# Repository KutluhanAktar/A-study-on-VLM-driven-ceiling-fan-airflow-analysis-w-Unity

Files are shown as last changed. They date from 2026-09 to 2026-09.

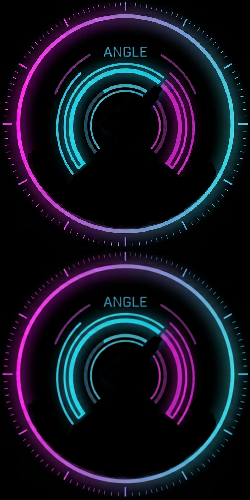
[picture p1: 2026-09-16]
Mobile Application/assets/angle_indicator_bg.png

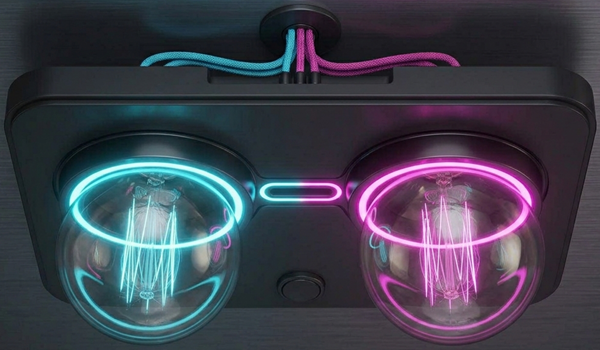
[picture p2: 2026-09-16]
Mobile Application/assets/dual_light_full_open.png

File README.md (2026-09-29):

> I developed my portfolio website — kutluhanaktar.com — from scratch and decided to migrate all of my codebase to GitHub to provide a simple and straightforward experimentation or replication method for my proof-of-concept projects. Nonetheless, since I focused on demonstrating my thought process and experiment results thoroughly in the written tutorial format, including but not limited to PCB and 3D model designing steps, I could not provide enough information to fully explain my concepts and instructions via GitHub descriptions only. Thus, I highly recommend inspecting the associated project tutorials and videos on my portfolio website or other platforms (maker communities), i.e., Hackster, Hackaday, and Instructables.

# Original Project Publication Date

**September 29, 2026**

# Description

**Utilizing VLMs to determine dual fan configurations for optimum cooling based on LiDAR-oriented real-time airflow simulations on Unity.**

As consecutive heatwaves were passing through my region at the beginning of Summer, I had been intrigued to develop a research project regarding AI-oriented HVAC simulations to increase real-world cooling efficiency both energy-wise and coverage-wise. Although there were meticulous research papers, even commercial firms providing services to analyze the cooling efficiency of air conditioning units by thorough HVAC simulations, I decided to focus on developing my project around ceiling fans. Even though ceiling fans are not as popular as air conditioning units nowadays, I had noticed there were a plethora of ceiling fan installations in my city, especially in historic shopping districts, bazaars, and government establishments. Thus, I decided to focus my research on simulating ceiling fan-induced airflow and deriving optimal system settings from this simulation for efficient cooling.

Considering I wanted to see the impact of AI-oriented simulations on deriving optimum configurations for a real-world ceiling fan system, I decided to design a dual ceiling fan mechanism from scratch, enabling me to control all experiment parameters while building my ceiling fan airflow simulation program. Though a little untraditional, I decided to base my dual ceiling fan design on a differential bevel gear mechanism to be able to move both fans 180° vertically and 360° horizontally, leading to a lot more complicated but comprehensive simulation-driven airflow analysis and real-world cooling efficiency improvements.

After deciding on the bare bones of the dual ceiling fan mechanism, I needed a method to map the surroundings of operating ceiling fans since a precise airflow simulation must include real-time obstacle updates to analyze airflow path fluctuations triggered by solid surfaces such as walls, open doors, windows, or even moving people. Generally, HVAC simulations for industrial settings utilize highly sensitive 3D LiDARs with SLAM or sensor fusion techniques to generate accurate heat maps. Nonetheless, since I wanted to focus on fan-produced indoor airflow analysis for much simpler settings, I decided to utilize an RPLIDAR A1M8-R6 LiDAR scanner and turn its 2D scan points into a simple 3D obstacle map in my airflow simulation program, enabling fan-produced air displacement routes (trails) to bounce off of their surfaces.

In the spirit of making the ceiling airflow simulation program easily accessible and open-source, I decided to utilize Unity to develop all airflow analysis features, including the obstacle generation from 2D LiDAR scan points, without utilizing any third-party or paid Unity services. Although Unity might seem like an odd choice since it is a cross-platform, performance-focused 3D game engine, I wanted to capitalize on its advanced scene and animation rendering features in order to simulate accurate airflow fluctuations and track fan-produced air displacement routes (trails). In this regard, I was able to obtain animation-based frames individually for each pre-defined ceiling fan configuration (angles, fan strength, etc.), enabling me to conduct airflow analysis by taking instances from a long animation (video) sequence.

To derive optimal ceiling fan configurations from selected airflow simulation frames so as to achieve real-world efficient cooling, I decided to utilize vision–language models (VLMs) running locally. As I wanted to demonstrate the performance of open-source vision–language models without tailoring model output for a specific ceiling fan-installed space, I did not train any models beforehand. In this regard, I was able to see whether off-the-shelf open-weight vision–language models could be deployed to obtain airflow simulation-based ceiling fan configurations to achieve energy-efficient and optimal cooling of a real-world closed environment. I thoroughly discussed my findings in the following tutorial, but I can briefly state that the vision-language models (Qwen) I employed performed well and provided effective fan configurations based on the obstacle map derived from 2D LiDAR scan points.

- Qwen2.5-VL-7B-Instruct
- Qwen3-VL-8B-Instruct

As I wanted to calculate 2D LiDAR scan points, execute the Unity ceiling fan-produced airflow simulation application, and run vision-language models on the same device to achieve fast and reliable simulation-based airflow analysis results, I decided to utilize the Qualcomm Dragonwing IQ-9075 Evaluation Kit (EVK), which is a compact development platform optimized for industrial IoT, Edge AI, and robotics applications involving heavy workloads. Thanks to the IQ-9075's dedicated AI Engine (Hexagon NPU) for on-device AI, I was able to execute operations separately to achieve excellent calculation, simulation, and inference performance, which is still bemusing to me considering the compactness of the EVK :)

To provide a user-friendly interface to select Unity-generated airflow simulation frames and communicate with the provided vision-language models, I developed a simple web application running on Flask, behaving as the intermediary between the Unity airflow simulation application and the local LLM/VLM server — Qualcomm Docker Compose container.

- Octa-core Kryo CPU ➡️ LiDAR scan points and other calculations
- Adreno GPU (with CPU) ➡️ Unity airflow simulation application
- Hexagon NPU ➡️ Vision-language models (VLMs)

Even though I obtained great airflow analysis results from vision-language models, I did not want to create a direct pipeline between the VLM outputs and ceiling fan mechanism controls, considering potential hallucinations and false positives. Furthermore, I wanted to enable the user to access all of the ceiling fan mechanism controls without impediments by not concealing fan configurations behind VLM outputs, including the dual light bulbs I added, since the ceiling fan with an on-device light source is a widely preferred household good. Since I did not want to create a secondary web-based interface for the fan configurations, I decided to develop a BLE-enabled mobile (Android) application, embedding the previously mentioned intermediary (Flask) web application. In this regard, all of the ceiling fan mechanism controls and VLM interactions can be inspected and adjusted on a single mobile application. The mobile application allows the user to:

- ✅ adjust ceiling fan vertical (180°) and horizontal (360°) angles for both fans,
- ✅ adjust ceiling fan strength magnitudes from 1 to 4,
- ✅ control light source states (on or off),
- ✅ observe current vertical angles and horizontal axis alignment states,
- ✅ connect to the intermediary web application to interact with the provided VLMs.

To enable the mobile application to manage ceiling fan mechanism configurations over BLE without putting any additional stress on the compute power of the IQ-9075 EVK, I decided to utilize a separate board, Arduino Nano 33 BLE, to control all mechanical features. I designed a unique 4-layer PCB to build a compact fan control unit based on the Nano 33 BLE, which provides all the required connections for the external power source, stepper motor drivers, DC motor drivers, lights, rotary encoders, optical speed modules, etc., to execute all of the ceiling fan mechanism features noted above.

As a proof-of-concept research project, I did not focus on building a directly installable ceiling fan system ready to cool an enclosed space like a commercially available product. Instead, I focused on developing a VLM-assisted ceiling fan mechanism that showcases intricate circuit connections, wiring, device structure, and a simulation-based airflow analysis pipeline. Thus, I immensely scaled down the intertwined VLM-assisted ceiling fan mechanism I envisioned and highlighted the fan elevation by placing the whole mechanism on an IKEA LACK table, which enabled me to create a highly detailed digital twin of the ceiling fan system in Fusion 360 and integrate this exquisite 3D model into the Unity Editor to develop an utterly accurate Unity airflow simulation application, estimating airflow fluctuations and air displacement routes (trails) based on the fan elevation and the LiDAR-detected obstacles.

# Inspect the project tutorial on:

- **[kutluhanaktar.com](https://www.kutluhanaktar.com/projects/A_study_on_VLM_driven_ceiling_fan_airflow_analysis_w_Unity/)**
- **[Hackster](https://www.hackster.io/kutluhan-aktar/a-study-on-vlm-driven-ceiling-fan-airflow-analysis-w-unity-9c8947)**
- **[Instructables](https://www.instructables.com/A-Study-on-VLM-driven-Ceiling-Fan-Airflow-Analysis/)**
- **[Arduino Project Hub](https://projecthub.arduino.cc/kutluhan_aktar)**
- **[Hackaday](https://hackaday.io/project/206717-a-study-on-vlm-driven-ceiling-fan-airflow-analysis)**

model_design_0<br>

model_design_3<br>

model_design_12_fan_mechanism<br>

model_design_35_fan_mechanism<br>

model_design_36_fan_mechanism<br>

assembly_68_fan_mechanism_diff<br>

unity_project_set_up_11_scale_color_mat<br>

unity_project_set_up_50_rplidar_a1_link_init_test<br>

unity_project_set_up_53_lidar_trail_tests<br>

iq9_software_setup_42_run_unity_app_box64<br>

iq9_software_setup_43_run_unity_app_box64<br>

assembly_142_legs<br>

device_run_1_test<br>

device_run_4_test<br>

android_app_run_10<br>

android_app_run_11<br>

android_app_run_12<br>

iq9_run_all_3_first_exp<br>

android_app_run_13<br>

android_app_run_15<br>

android_app_run_16<br>

android_app_run_18<br>

android_app_run_20<br>

android_app_run_21<br>

android_app_run_23<br>

android_app_run_24<br>

android_app_run_25<br>

android_app_run_27<br>

android_app_run_29_cont<br>

device_run_11_fan_movement<br>

android_app_run_35_cont<br>

device_run_16_fan_movement<br>

android_app_run_39_cont<br>

device_run_19_fan_movement<br>

android_app_run_46_cont<br>

device_run_23_fan_movement<br>

android_app_run_51_cont<br>

device_run_29_lights<br>

android_app_run_54_cont<br>

device_run_37_angle_zeroing<br>

android_app_run_56_cont<br>

device_run_40_scnerio_2_door_open<br>

iq9_run_all_9_second_exp<br>

android_app_run_58_scenerio_2<br>

device_run_41_scnerio_2_door_closed<br>

iq9_run_all_12_second_exp_door_closed<br>

android_app_run_61_scenerio_2_8b<br>

android_app_run_64_scenerio_2_8b<br>

android_app_run_66_scenerio_2_8b<br>

iq9_run_all_13_second_exp_recorded<br>

device_run_42_scnerio_3_cam_move<br>

iq9_run_all_18_third_exp_camera_pos_change<br>

android_app_run_72_scenerio_3_cam_move

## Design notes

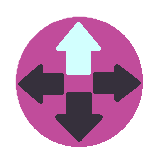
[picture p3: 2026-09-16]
Mobile Application/assets/fan_joystick_knob_c_up.png

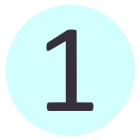
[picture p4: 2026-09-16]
Mobile Application/assets/fan_slider_knob_1.png

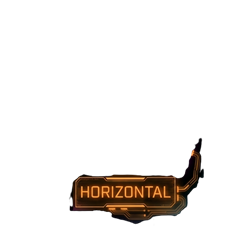
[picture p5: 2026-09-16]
Mobile Application/assets/angle_indicator_homed.png

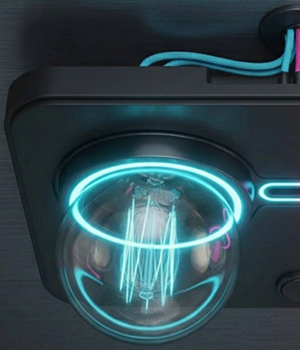
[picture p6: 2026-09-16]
Mobile Application/assets/dual_light_left_open.png

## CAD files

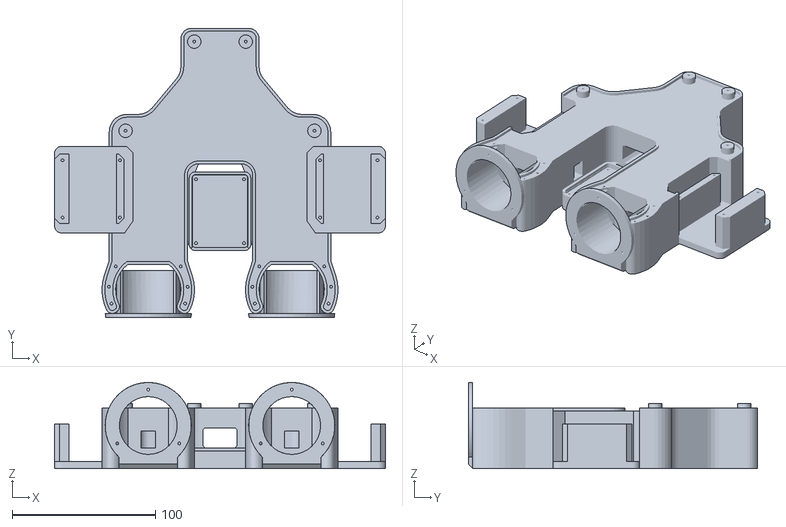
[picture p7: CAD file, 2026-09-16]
Mechanical Components/STL/central_fan_control_unit/ceiling_fan_mechanism v98_ceiling_fan_mechanism v98_central_fan_control_unit_1_main.stl
230.7 x 201.7 x 60.0

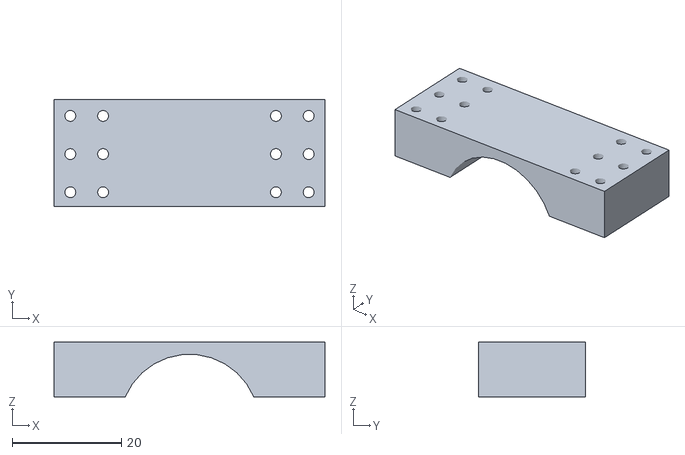
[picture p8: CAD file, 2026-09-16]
Mechanical Components/STL/fan_driver_mechanism/ceiling_fan_mechanism v98_ceiling_fan_mechanism v98_fan_driver_mechanism_1_joint_carrier_gear_cap.stl
49.7 x 19.6 x 10.00

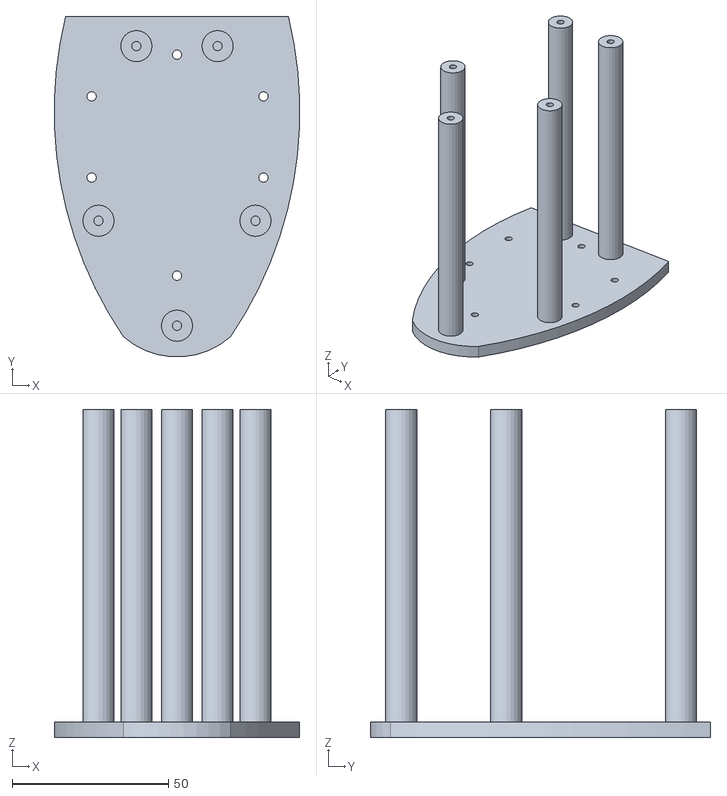
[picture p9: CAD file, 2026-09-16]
Mechanical Components/STL/lidar_stand/ceiling_fan_mechanism v98_ceiling_fan_mechanism v98_lidar_stand_1_stand.stl
78.5 x 108.9 x 105.0

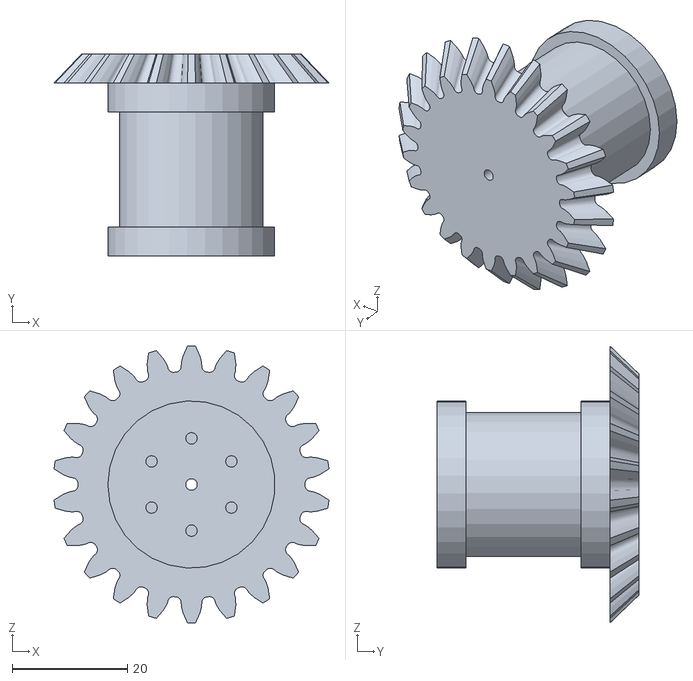
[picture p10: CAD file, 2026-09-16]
Mechanical Components/STL/fan_driver_mechanism/ceiling_fan_mechanism v98_ceiling_fan_mechanism v98_fan_driver_mechanism_1_driver_carrier_bevel_gear.stl
47.7 x 35.0 x 48.0

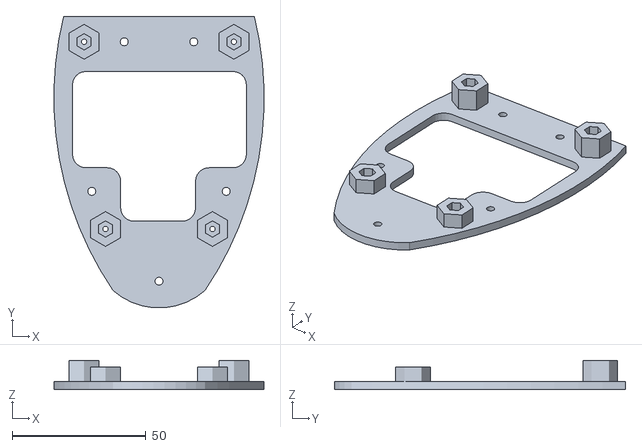
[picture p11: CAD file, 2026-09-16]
Mechanical Components/STL/lidar_stand/ceiling_fan_mechanism v98_ceiling_fan_mechanism v98_lidar_stand_1_mount.stl
78.5 x 108.9 x 11.0

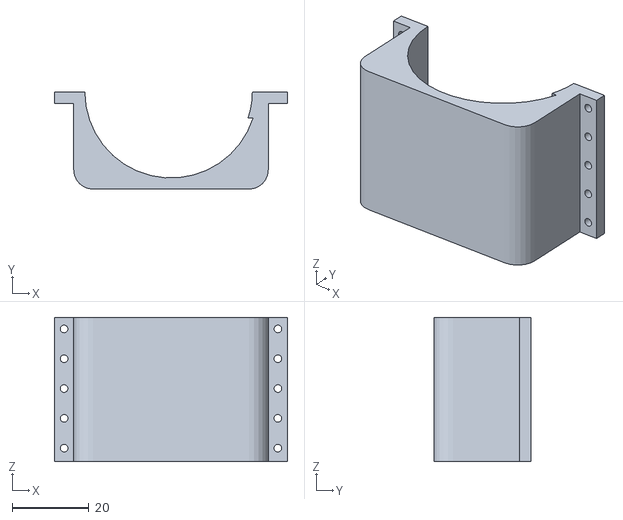
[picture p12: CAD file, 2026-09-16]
Mechanical Components/STL/fan_driver_mechanism/ceiling_fan_mechanism v98_ceiling_fan_mechanism v98_fan_driver_mechanism_1_fan_motor_holder_top.stl
60.6 x 25.3 x 37.5

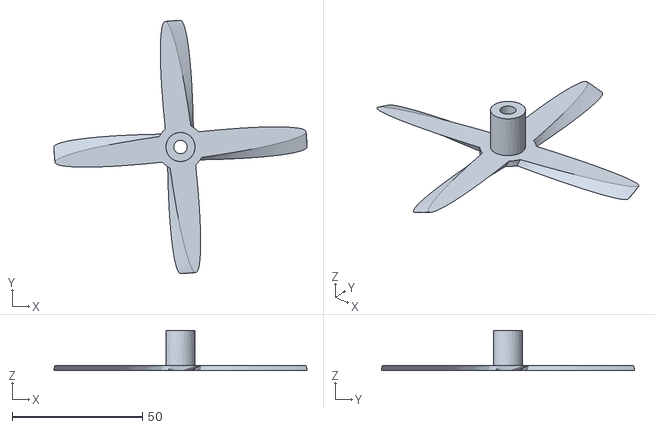
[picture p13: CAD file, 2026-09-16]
Mechanical Components/STL/fan_driver_mechanism/ceiling_fan_mechanism v98_ceiling_fan_mechanism v98_fan_driver_mechanism_1_fan_blades.stl
97.0 x 97.0 x 15.5

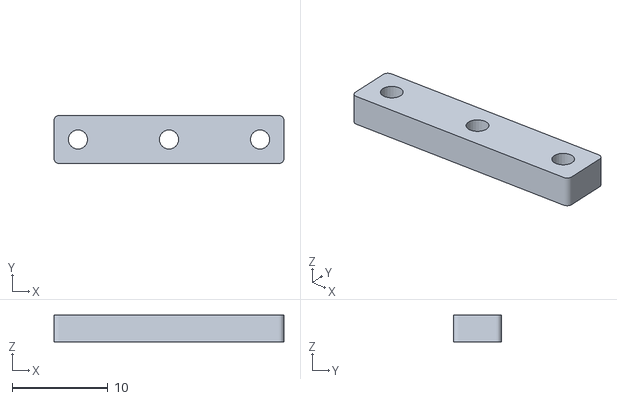
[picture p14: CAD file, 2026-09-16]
Mechanical Components/STL/fan_driver_mechanism/ceiling_fan_mechanism v98_ceiling_fan_mechanism v98_fan_driver_mechanism_1_joint_carrier_support_4.stl
24.0 x 5.00 x 2.80

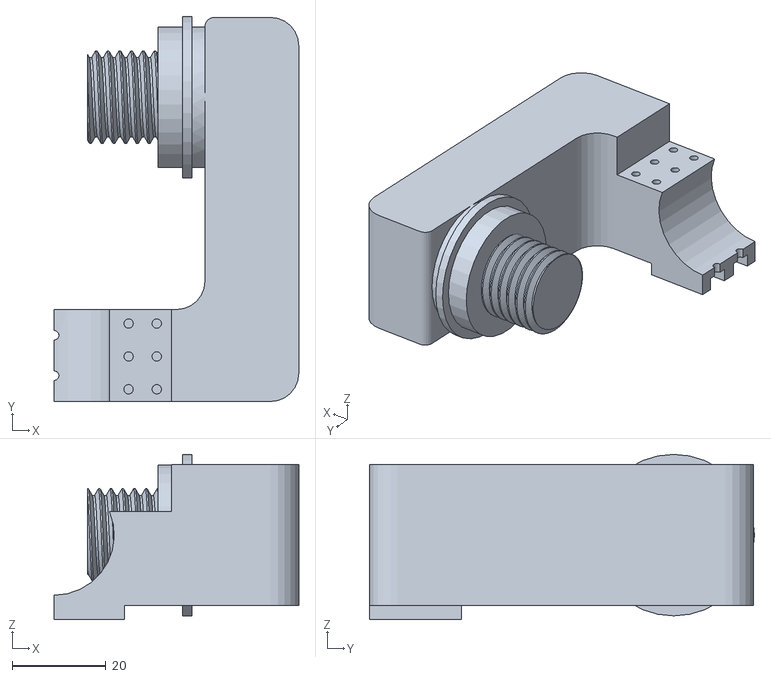
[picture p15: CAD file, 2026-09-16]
Mechanical Components/STL/fan_driver_mechanism/ceiling_fan_mechanism v98_ceiling_fan_mechanism v98_fan_driver_mechanism_1_joint_carrier_l.stl
52.1 x 82.0 x 35.2

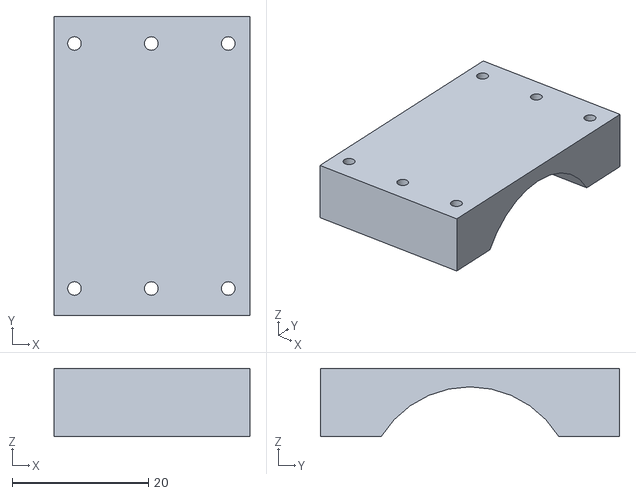
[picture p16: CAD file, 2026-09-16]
Mechanical Components/STL/fan_driver_mechanism/ceiling_fan_mechanism v98_ceiling_fan_mechanism v98_fan_driver_mechanism_1_joint_carrier_pivot_cap.stl
28.8 x 44.0 x 10.0

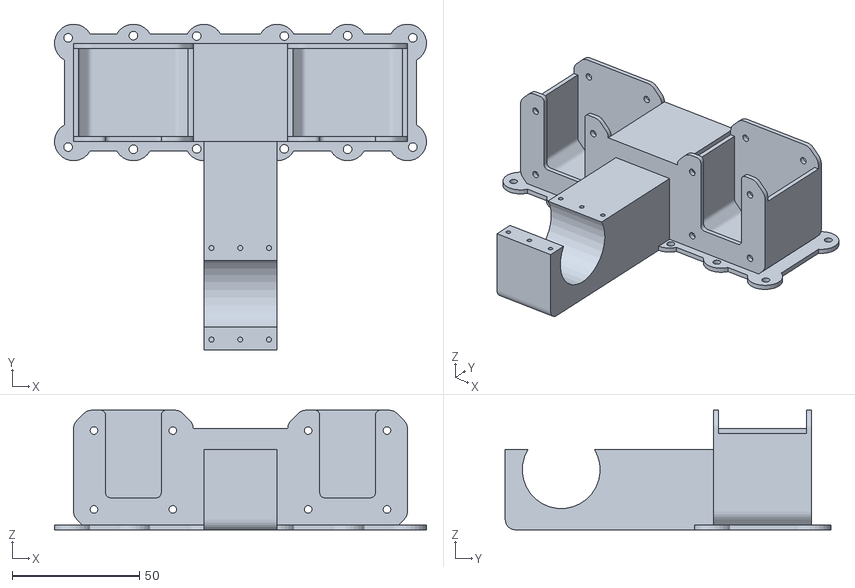
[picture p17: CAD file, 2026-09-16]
Mechanical Components/STL/fan_driver_mechanism/ceiling_fan_mechanism v98_ceiling_fan_mechanism v98_fan_driver_mechanism_1_primary_carrier.stl
146.3 x 128.0 x 47.1

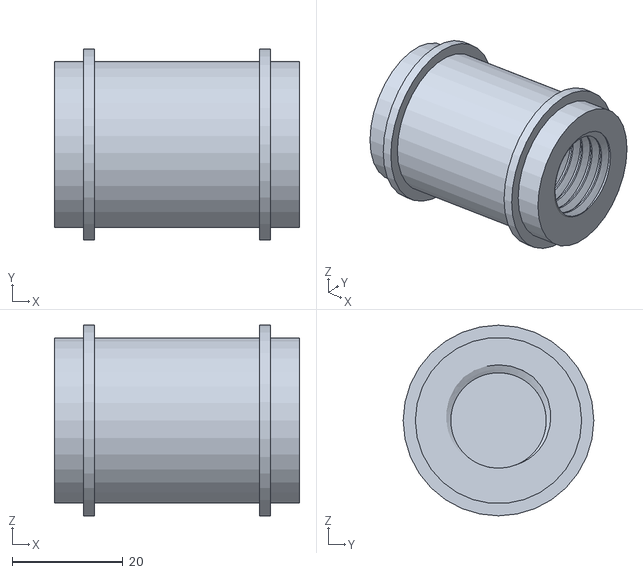
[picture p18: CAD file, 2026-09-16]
Mechanical Components/STL/fan_driver_mechanism/ceiling_fan_mechanism v98_ceiling_fan_mechanism v98_fan_driver_mechanism_1_joint_carrier_pivot.stl
44.2 x 34.4 x 34.4

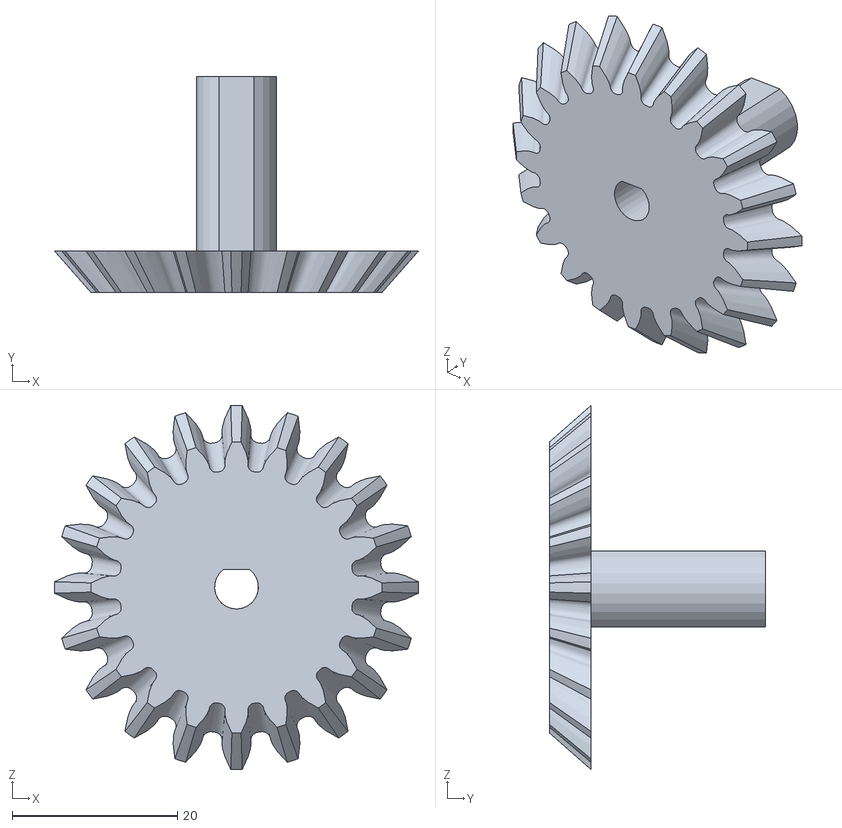
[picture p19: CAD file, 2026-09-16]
Mechanical Components/STL/fan_driver_mechanism/ceiling_fan_mechanism v98_ceiling_fan_mechanism v98_fan_driver_mechanism_1_driver_bevel_gear.stl
44.0 x 26.1 x 44.0

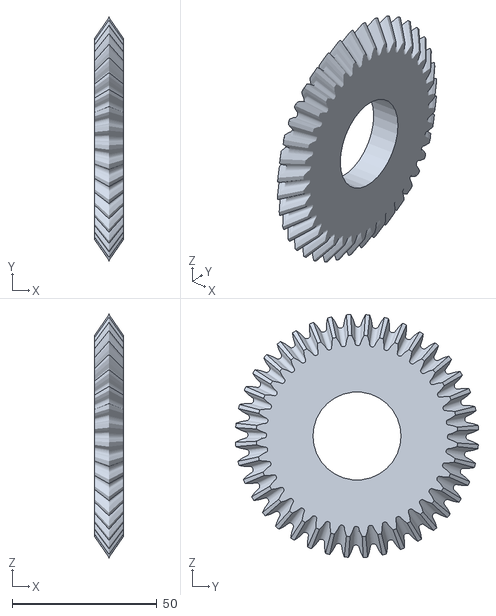
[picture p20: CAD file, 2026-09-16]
Mechanical Components/STL/fan_driver_mechanism/ceiling_fan_mechanism v98_ceiling_fan_mechanism v98_fan_driver_mechanism_1_angle_bevel_gear.stl
10.0 x 83.9 x 83.9

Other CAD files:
Mechanical Components/STL/fan_driver_mechanism/ceiling_fan_mechanism v98_ceiling_fan_mechanism v98_fan_driver_mechanism_1_joint_angle_calibration_stand.stl
Mechanical Components/STL/fan_driver_mechanism/ceiling_fan_mechanism v98_ceiling_fan_mechanism v98_fan_driver_mechanism_1_joint_carrier_support_3.stl
Mechanical Components/STL/fan_driver_mechanism/ceiling_fan_mechanism v98_ceiling_fan_mechanism v98_fan_driver_mechanism_1_joint_carrier_r.stl
Mechanical Components/STL/fan_driver_mechanism/ceiling_fan_mechanism v98_ceiling_fan_mechanism v98_fan_driver_mechanism_1_fan_motor_holder_bottom.stl
Mechanical Components/STL/fan_driver_mechanism/ceiling_fan_mechanism v98_ceiling_fan_mechanism v98_fan_driver_mechanism_1_joint_angle_calibration_pins.stl

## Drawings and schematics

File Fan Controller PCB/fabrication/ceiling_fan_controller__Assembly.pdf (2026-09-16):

1 | 2 | 3 | 4 | 5 | 6

A

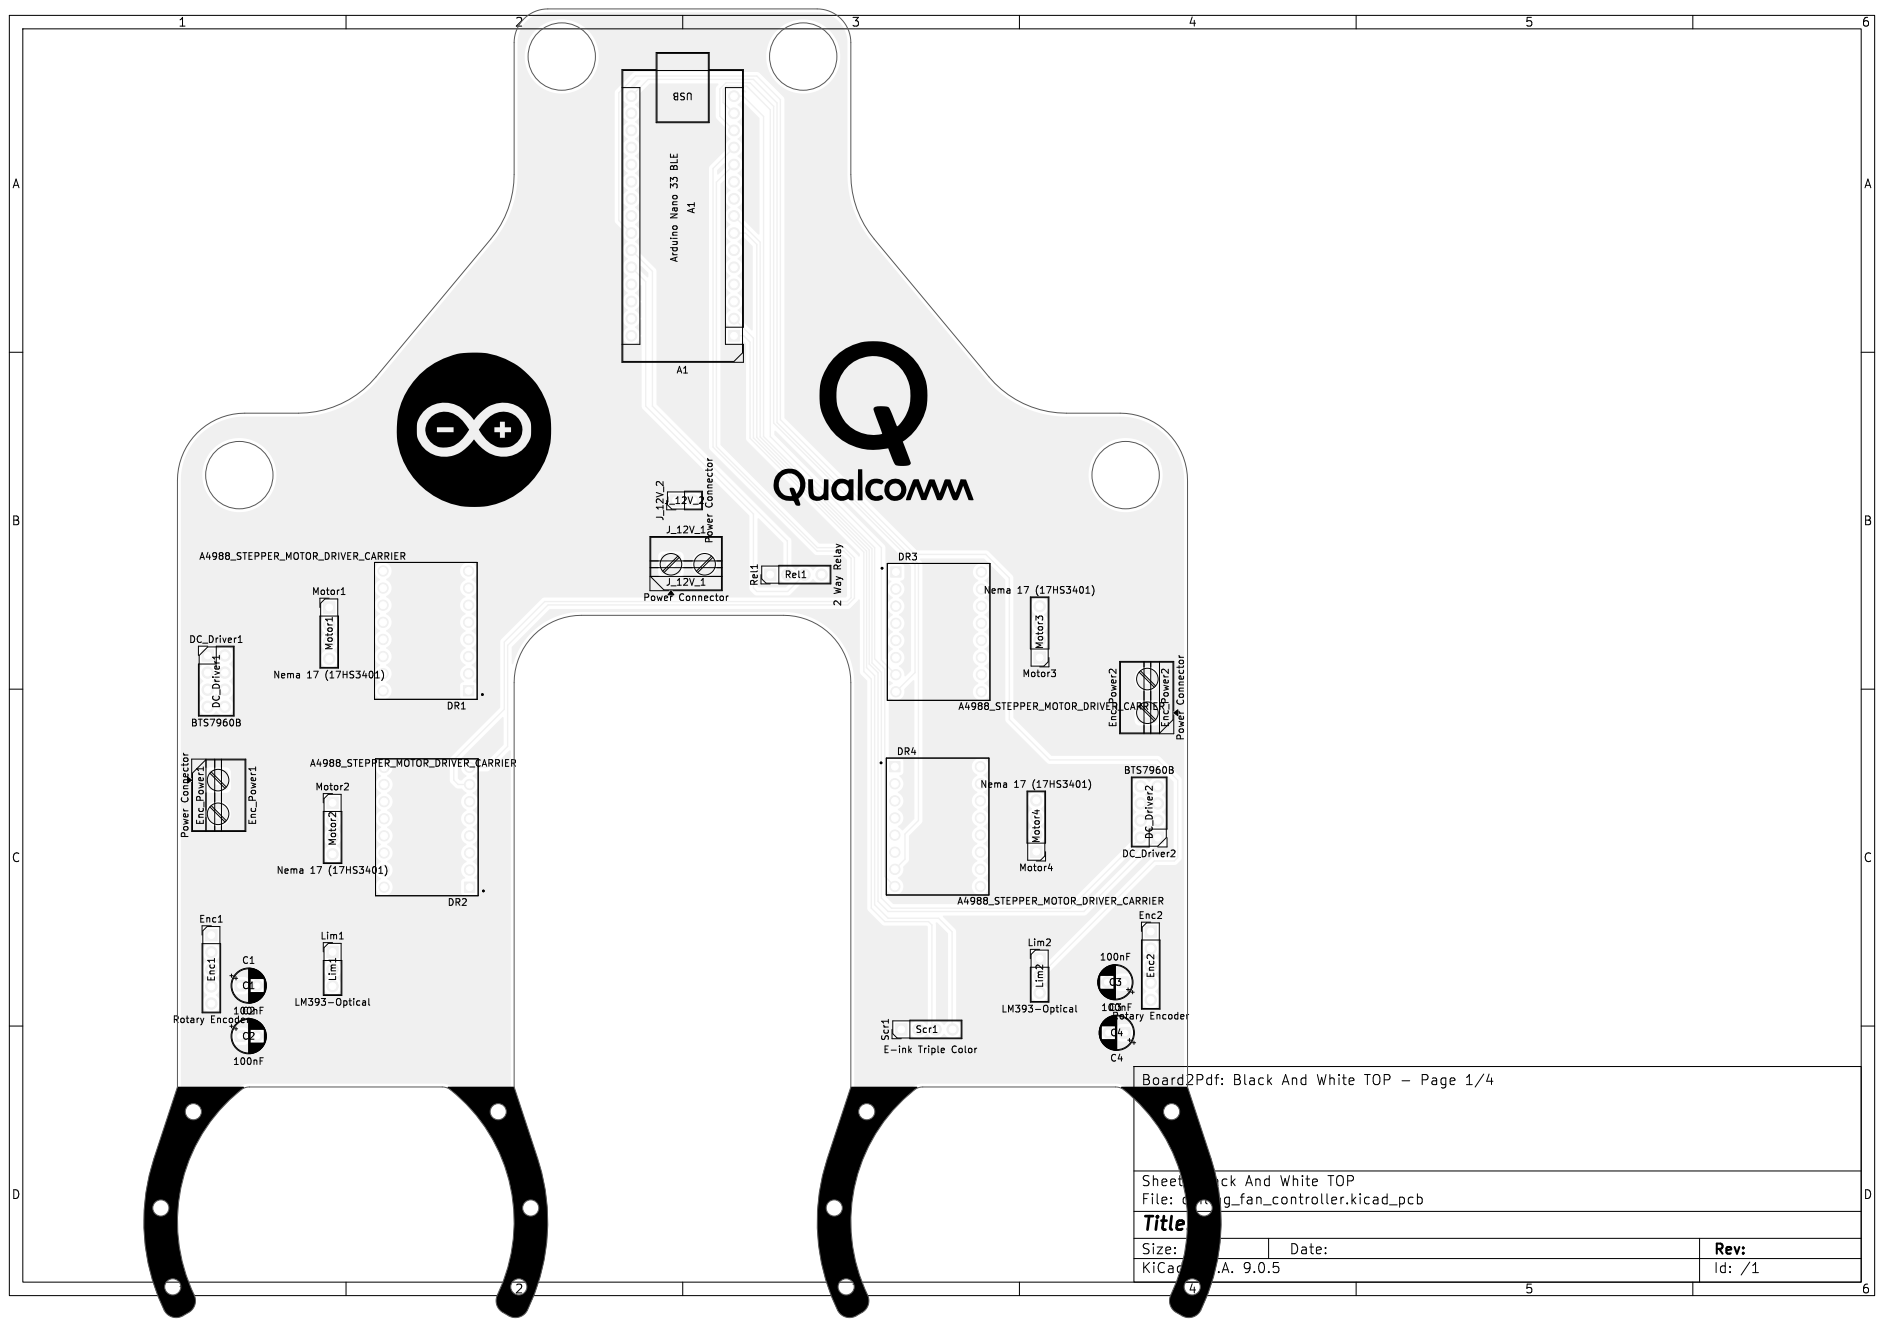
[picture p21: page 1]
Scr1 DC_Driver2 C1 Motor2 Enc_Power1 Rel1 C4 DR1 J_12V_2 J_12V_1 Motor1 DR2 C3; Lim1; Enc2 Enc_Power2 DR4; Motor3 Motor4 DC_Driver1; A1 USB; Lim2 DR3 C2 Enc1; D Date: KiCad; E.D.A. 9.0.5 Size: A4; Rev:; Id: /1 Title: File: ceiling_fan_controller.kicad_pcb Sheet: Black; And; White; TOP; Board2Pdf:; Black; TOP -; Page; E-ink; Triple Color Scr1; BTS7960B DC_Driver2; Nema 17 (17HS3401) Motor2 Power Connector; Enc_Power1; 2 Way Relay Rel1; A4988_STEPPER_MOTOR_DRIVER_CARRIER; Power J_12V_2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

A

A

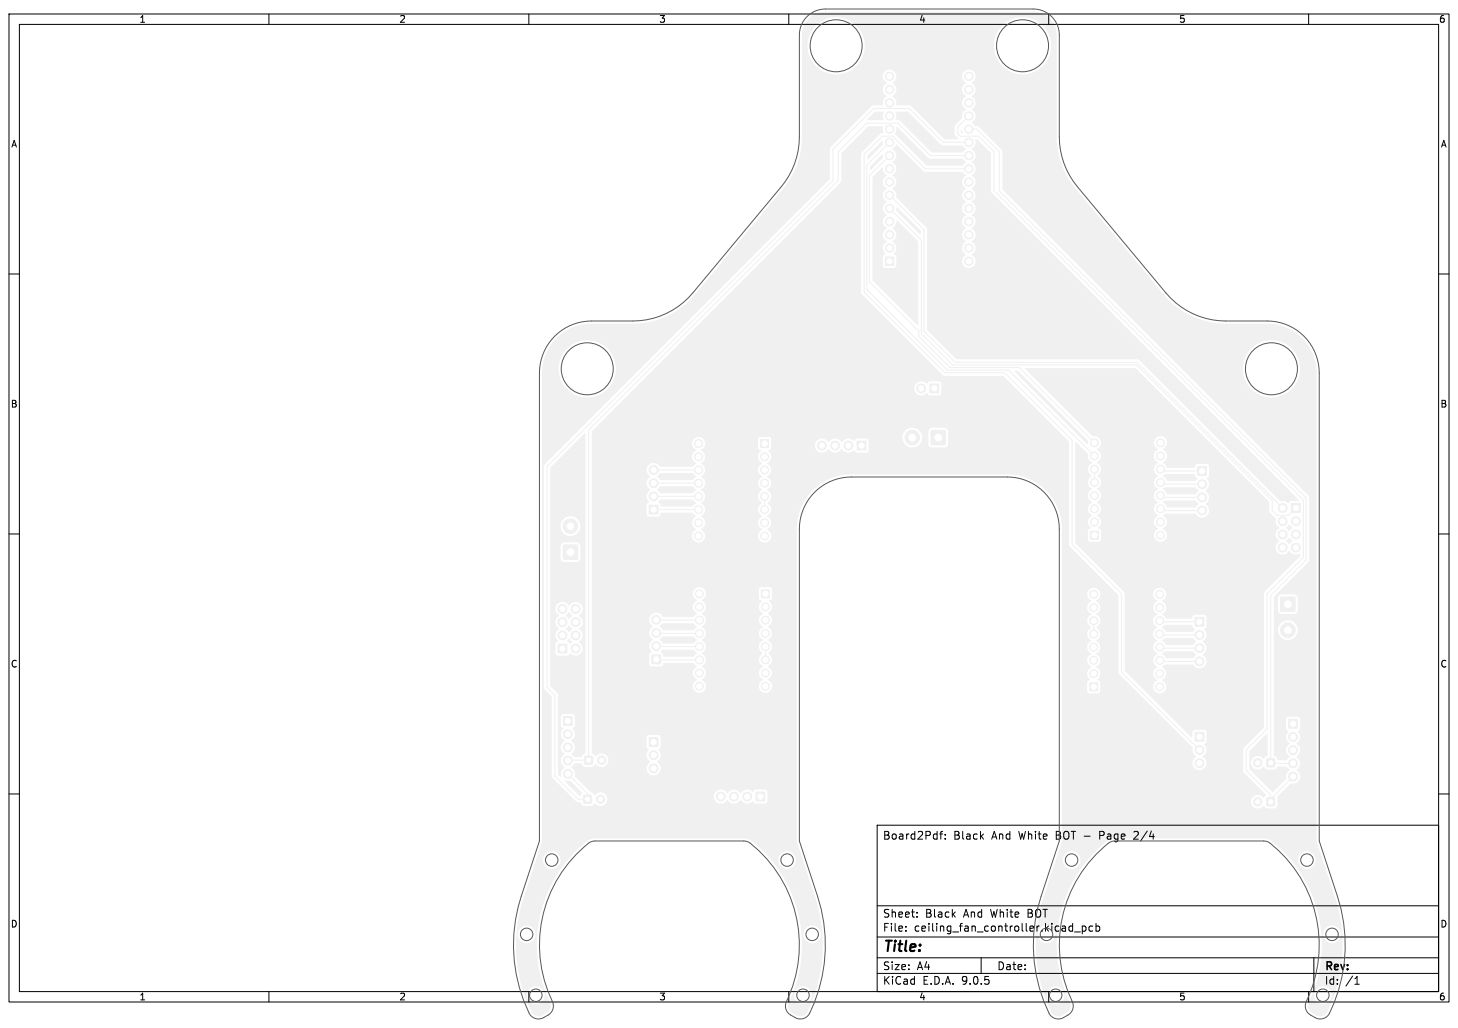
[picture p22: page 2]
D Date: KiCad; E.D.A. 9.0.5 Size: A4; Rev:; Id: /1 Title: File: ceiling_fan_controller.kicad_pcb Sheet: Black; And; White; BOT Board2Pdf:; Black; BOT -; Page 2/4

A

A

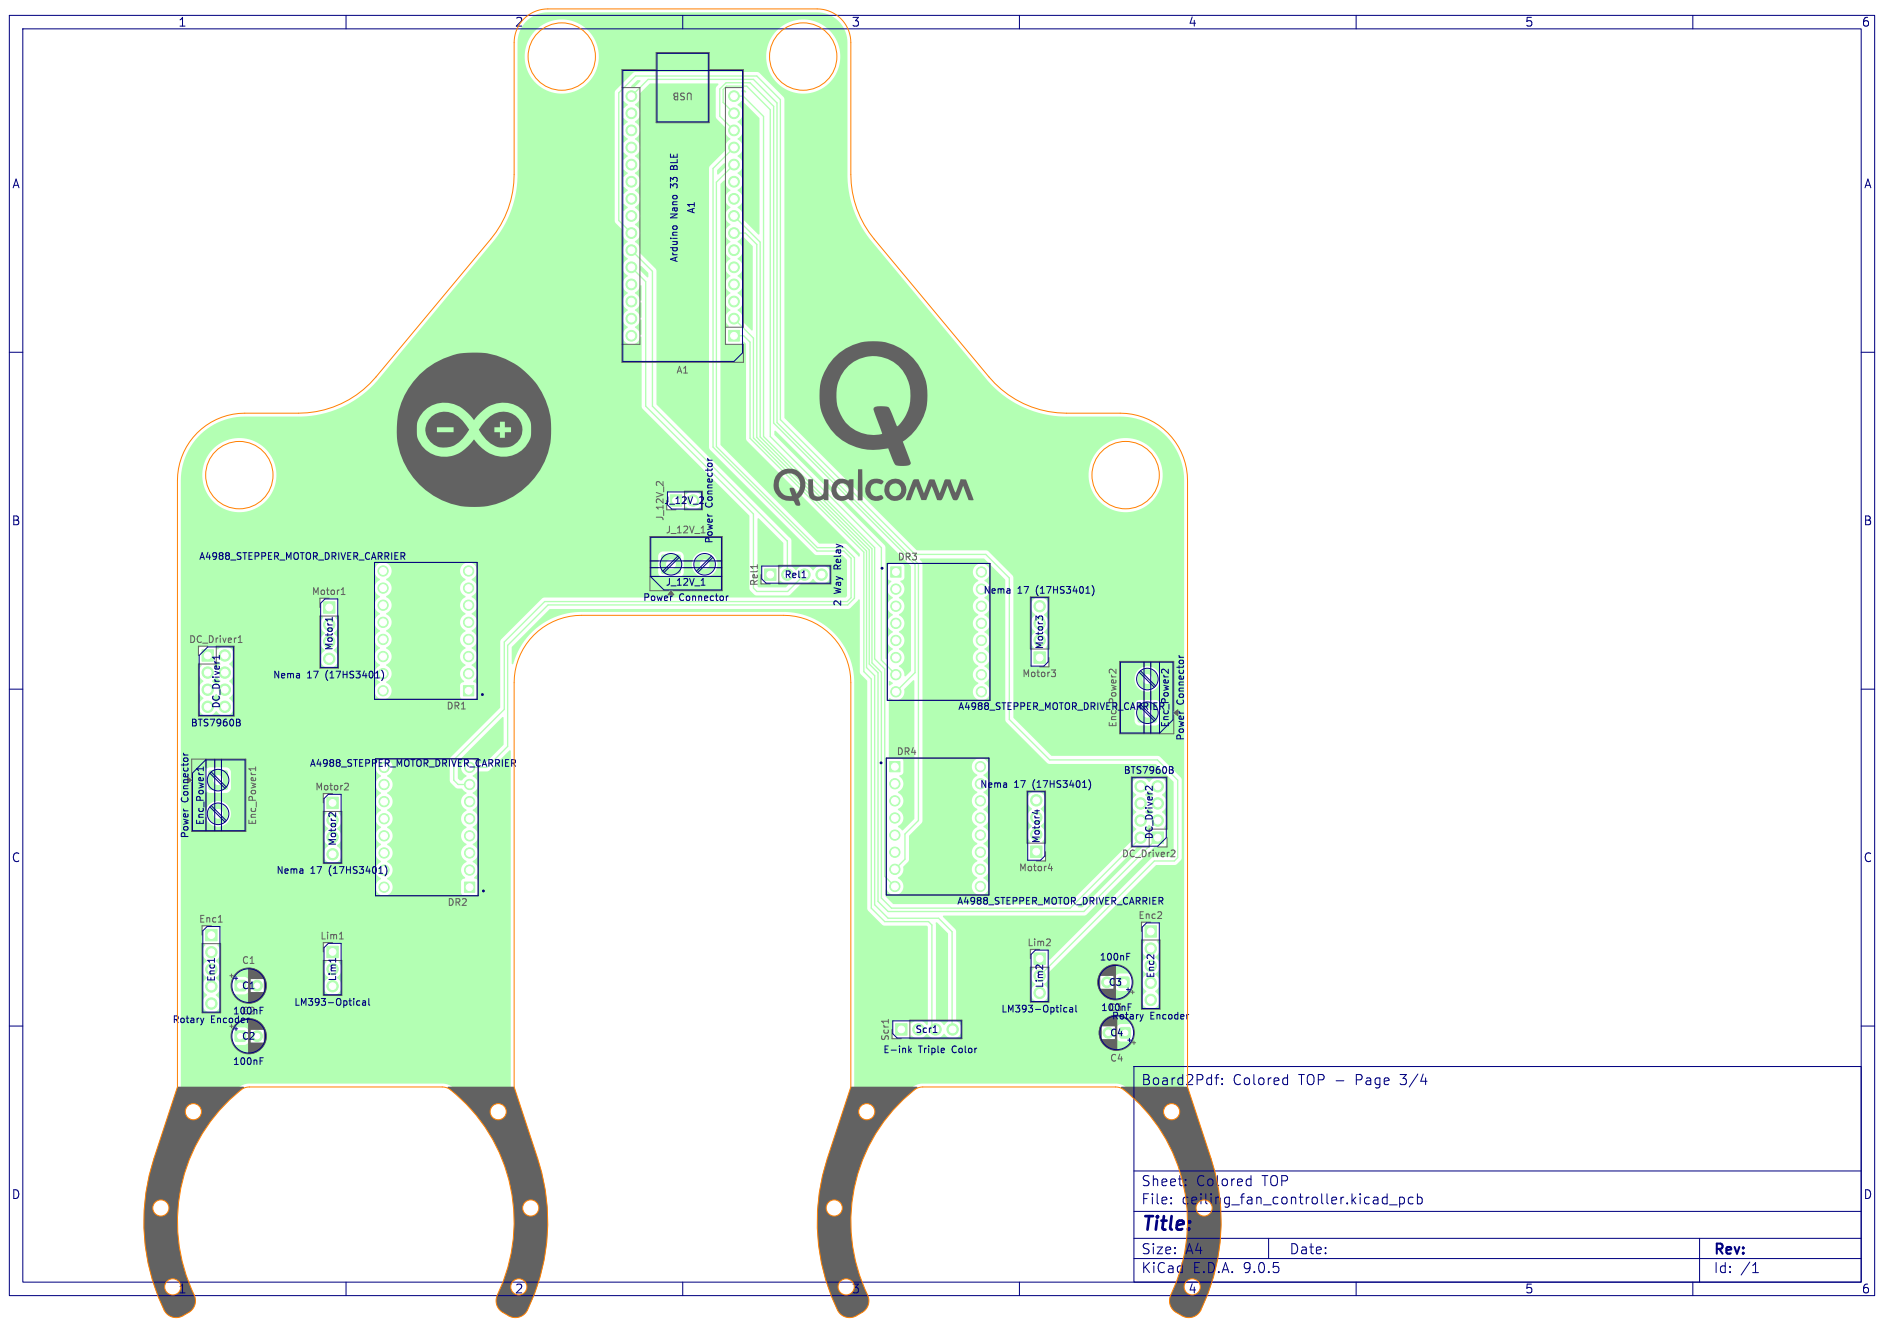
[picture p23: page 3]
Scr1 DC_Driver2 C1 Motor2 Enc_Power1 Rel1 C4 DR1 J_12V_2 J_12V_1 Motor1 DR2 C3; Lim1; Enc2 Enc_Power2 DR4; Motor3 Motor4 DC_Driver1; A1 USB; Lim2 DR3 C2 Enc1; D Date: KiCad; E.D.A. 9.0.5 Size: A4; Rev:; Id: /1 Title: File: ceiling_fan_controller.kicad_pcb Sheet: Colored; TOP; Board2Pdf:; Colored; TOP -; Page 3/4; E-ink; Triple Color Scr1; BTS7960B DC_Driver2; Nema 17 (17HS3401) Motor2 Power Connector; Enc_Power1; 2 Way Relay Rel1; A4988_STEPPER_MOTOR_DRIVER_CARRIER; Power J_12V_2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

A

A

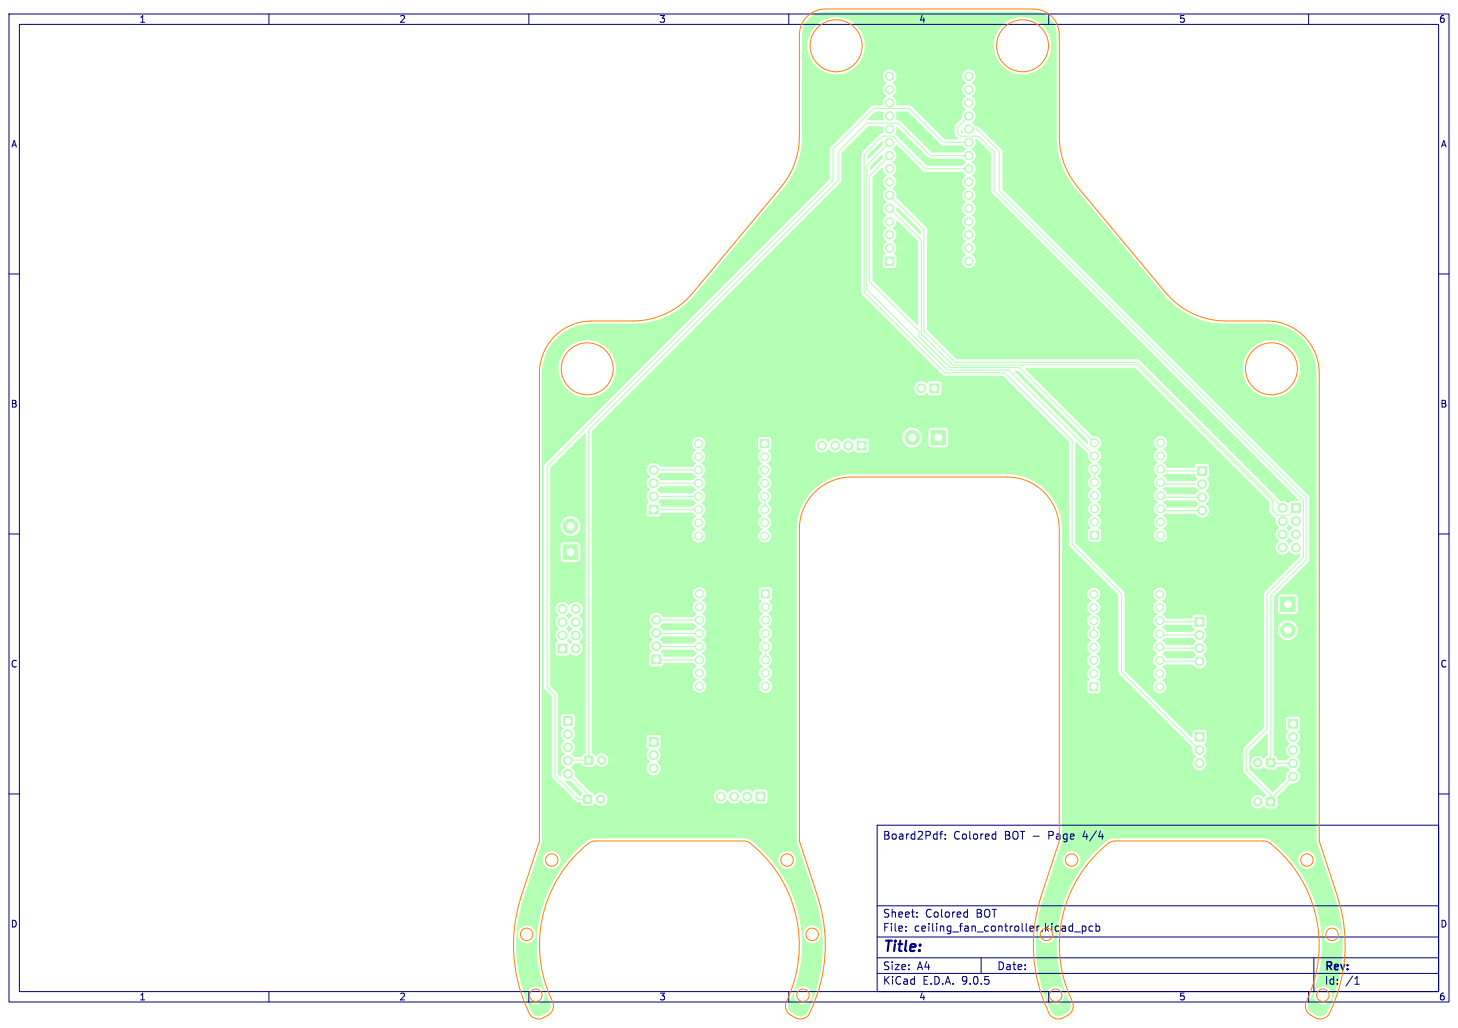
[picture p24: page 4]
D Date: KiCad; E.D.A. 9.0.5 Size: A4; Rev:; Id: /1 Title: File: ceiling_fan_controller.kicad_pcb Sheet: Colored; BOT Board2Pdf:; Colored; BOT -; Page 4/4

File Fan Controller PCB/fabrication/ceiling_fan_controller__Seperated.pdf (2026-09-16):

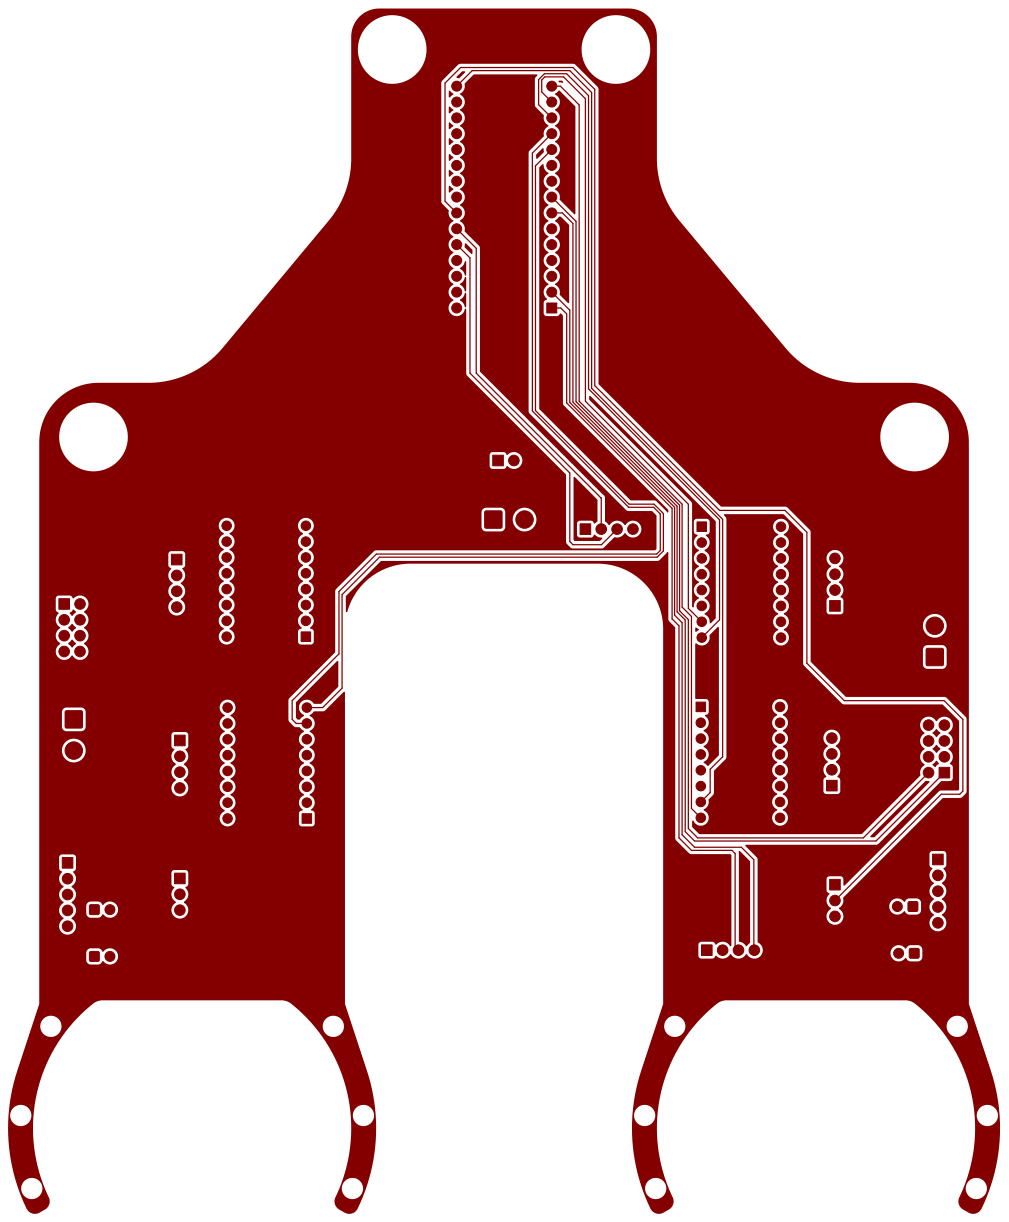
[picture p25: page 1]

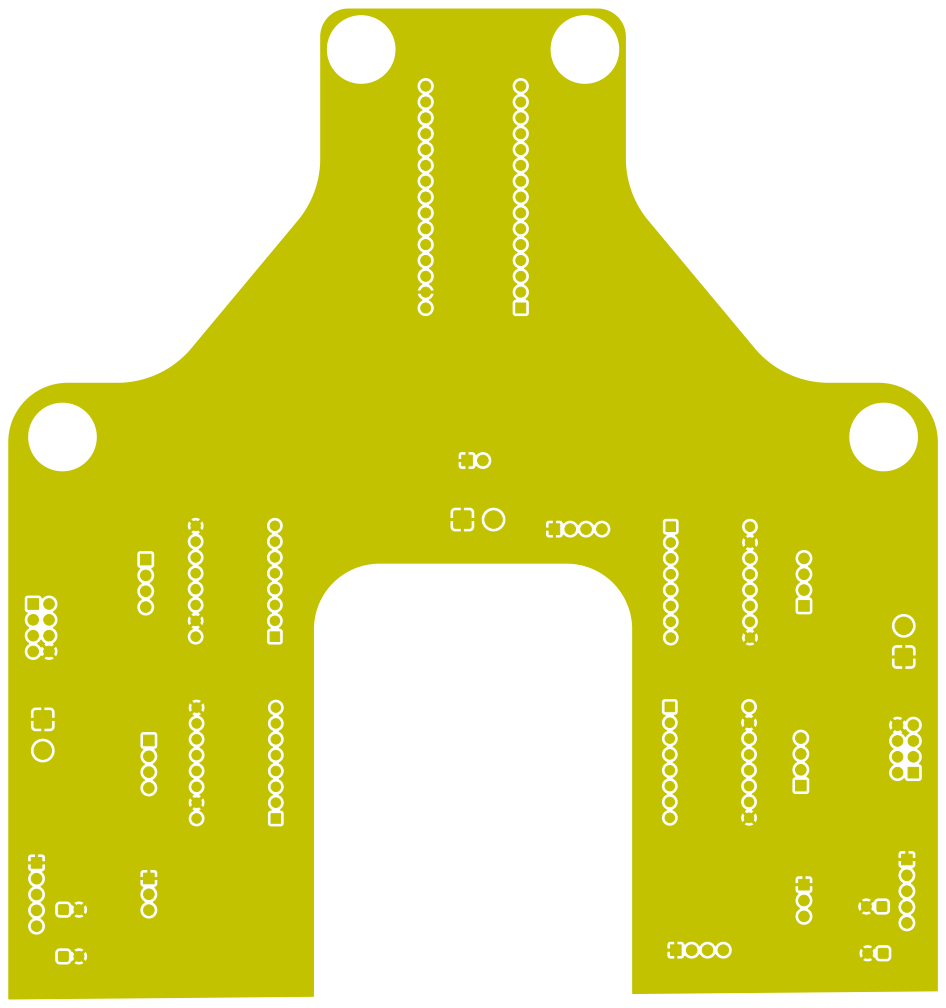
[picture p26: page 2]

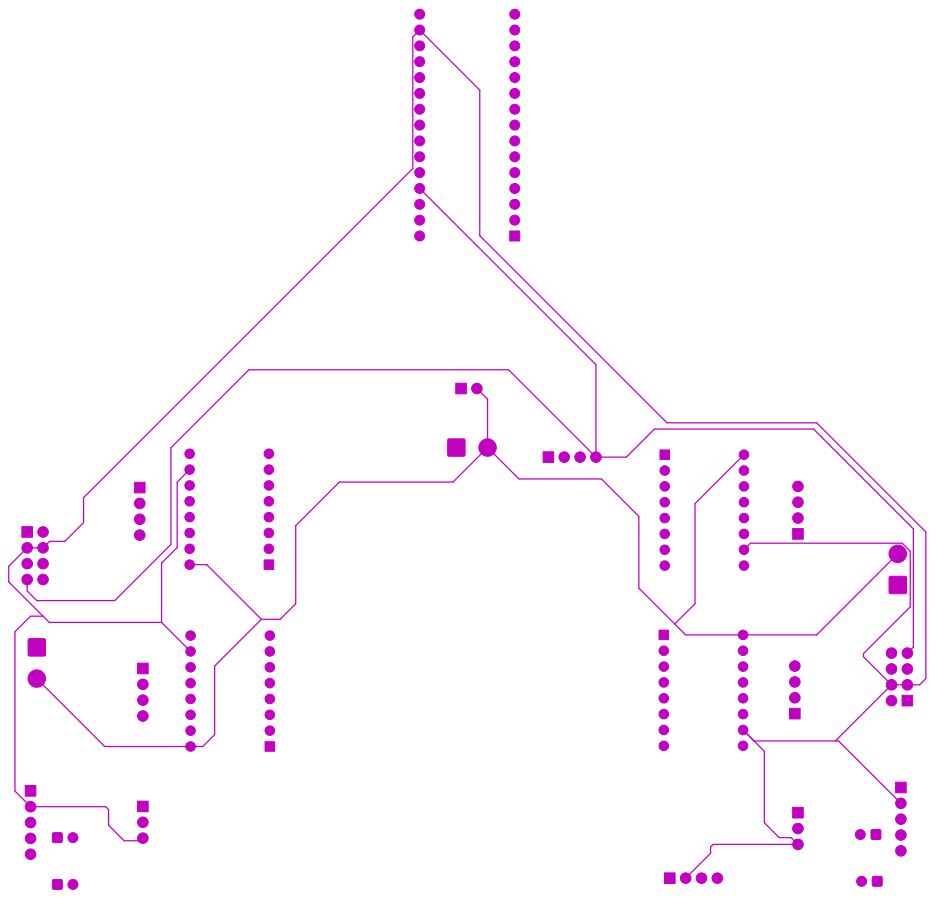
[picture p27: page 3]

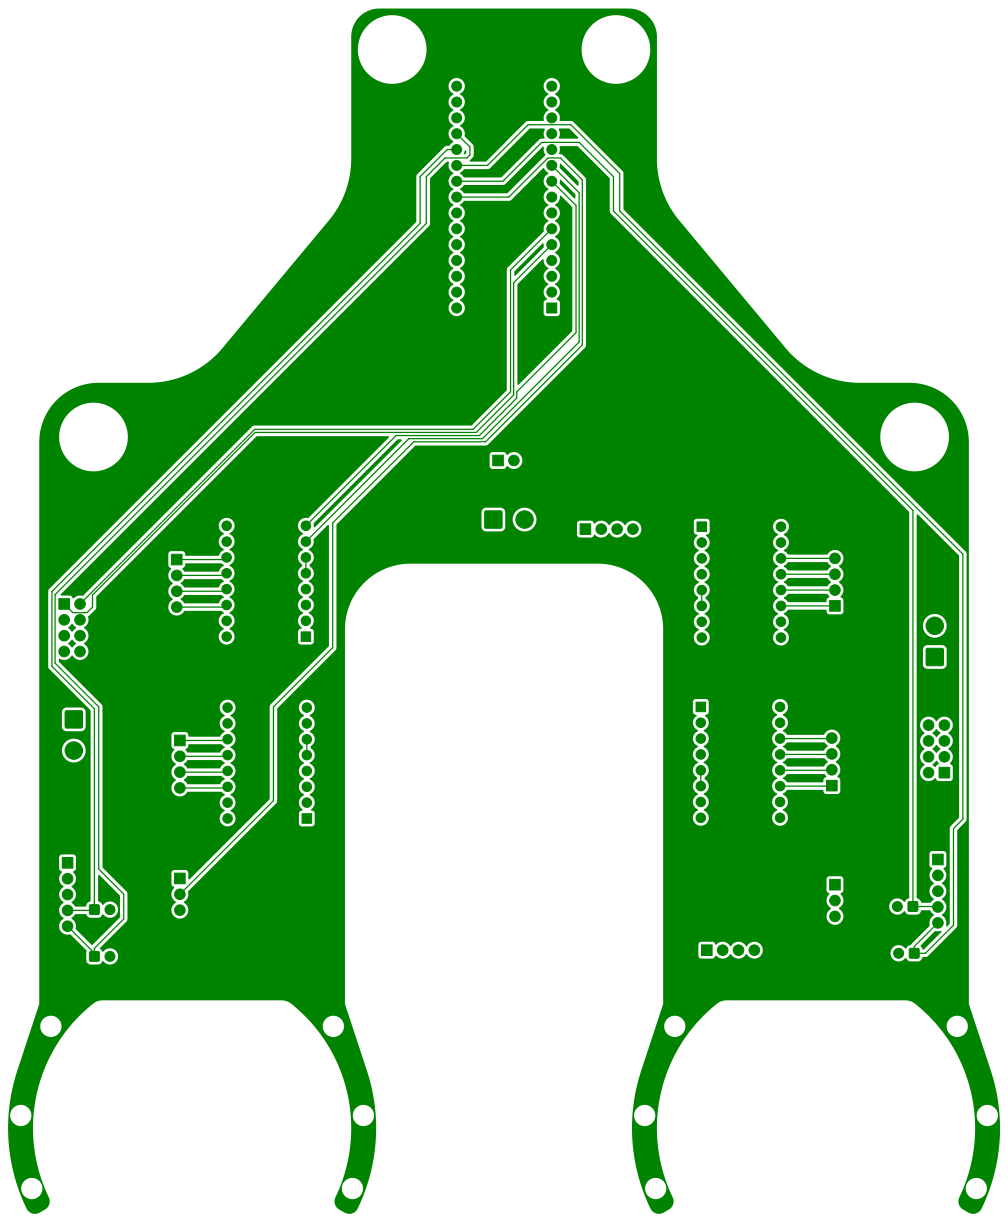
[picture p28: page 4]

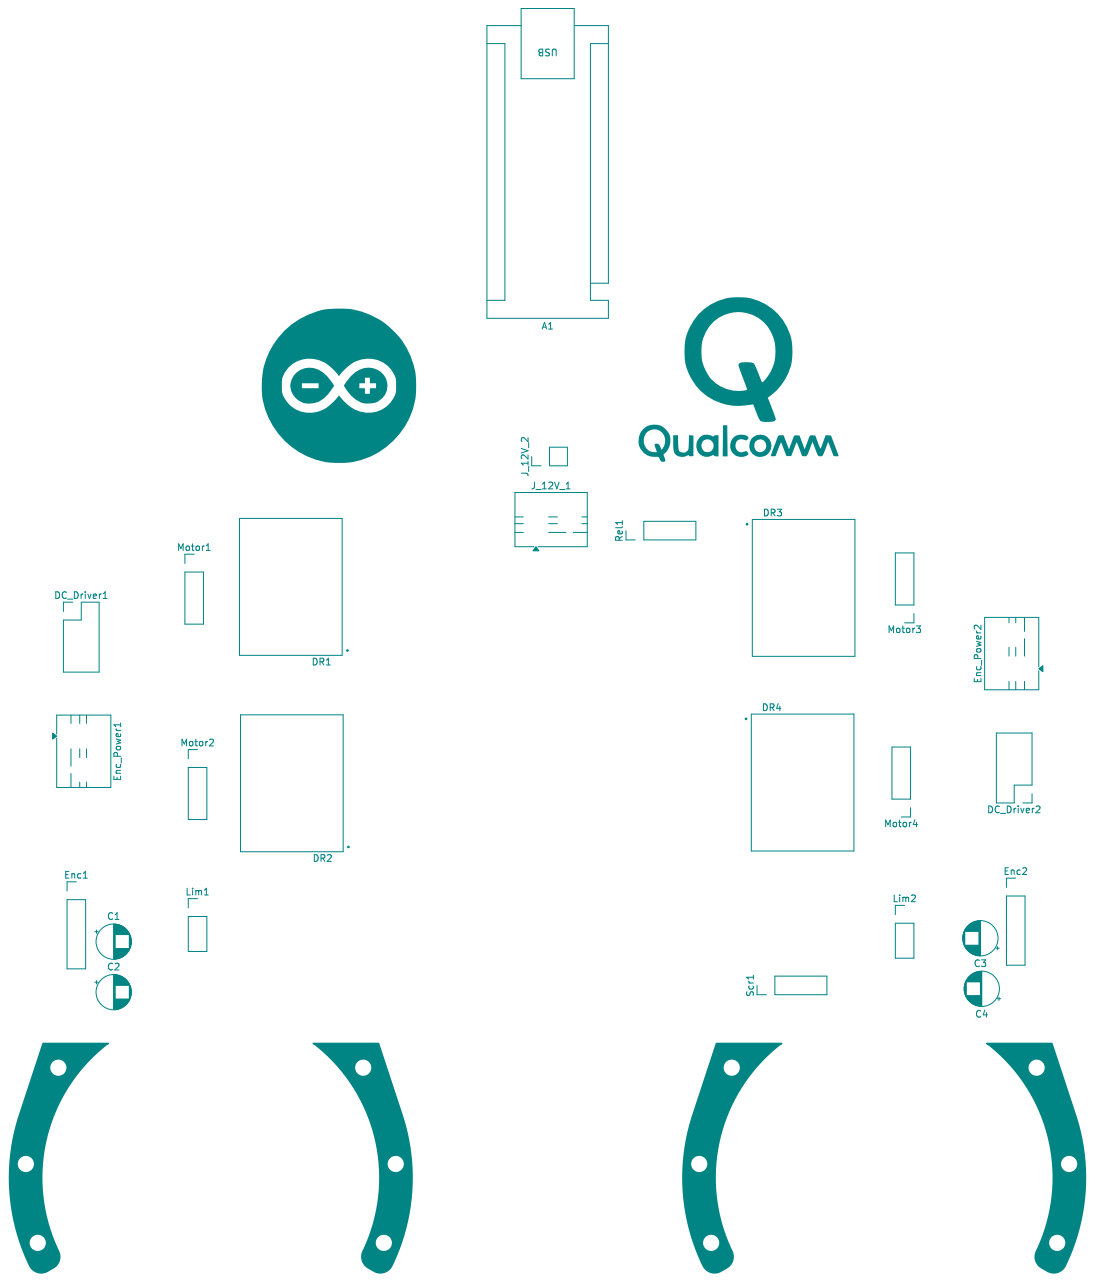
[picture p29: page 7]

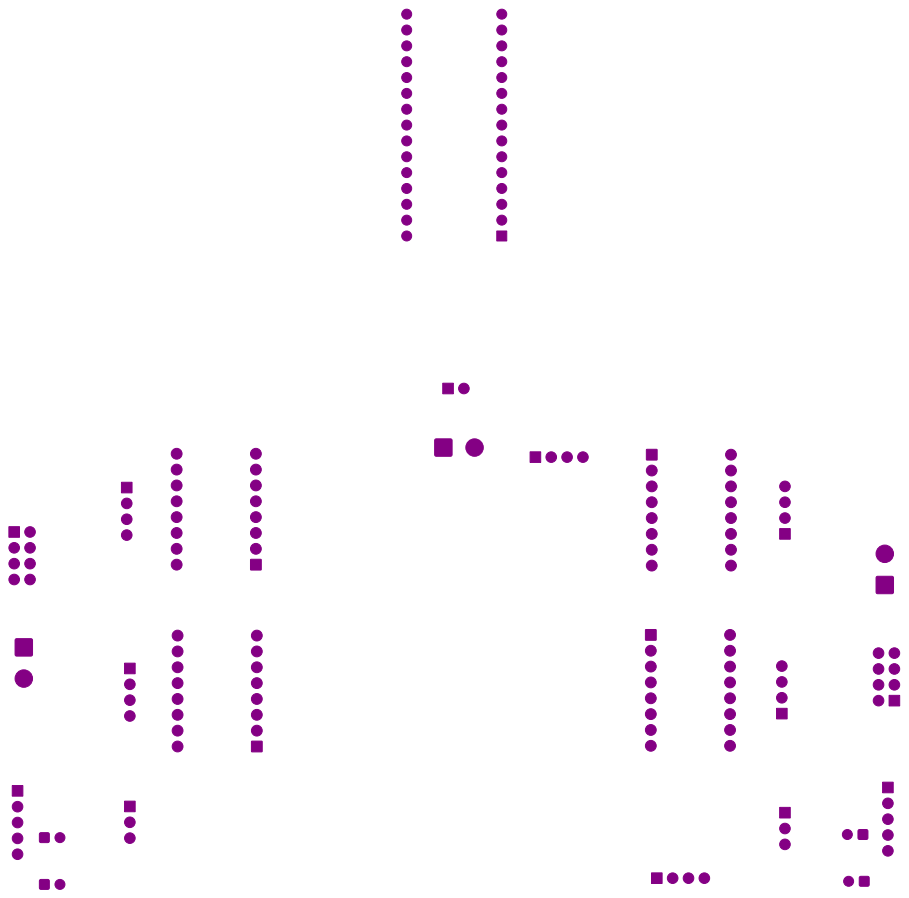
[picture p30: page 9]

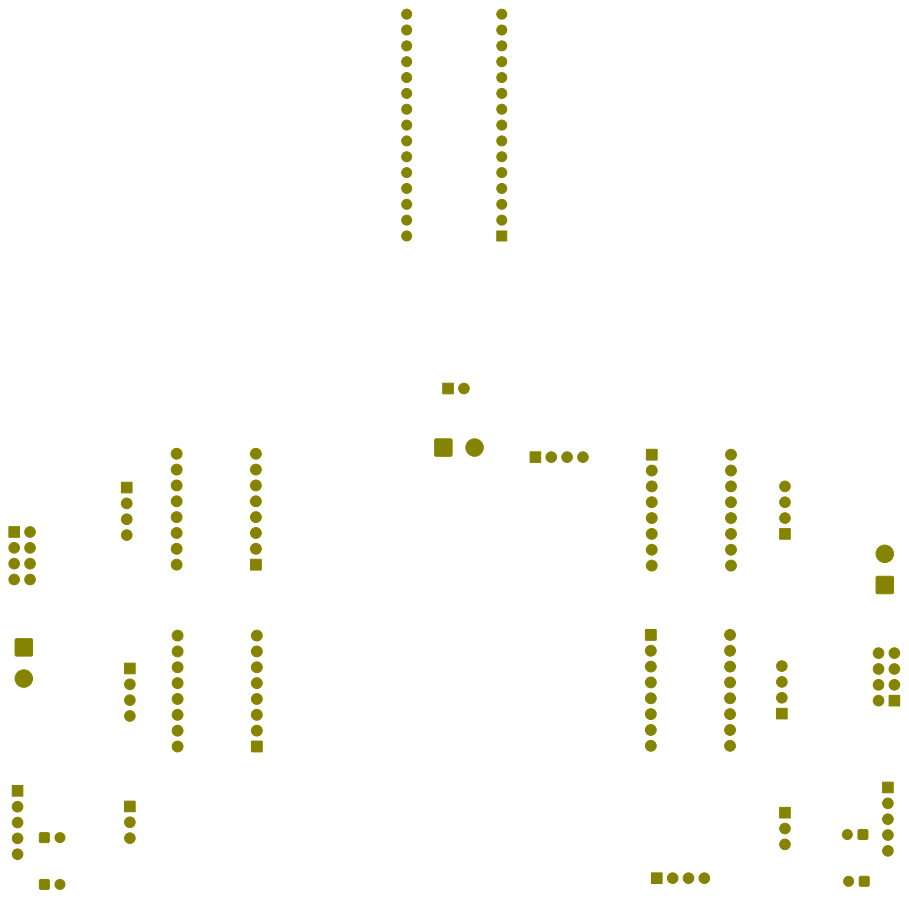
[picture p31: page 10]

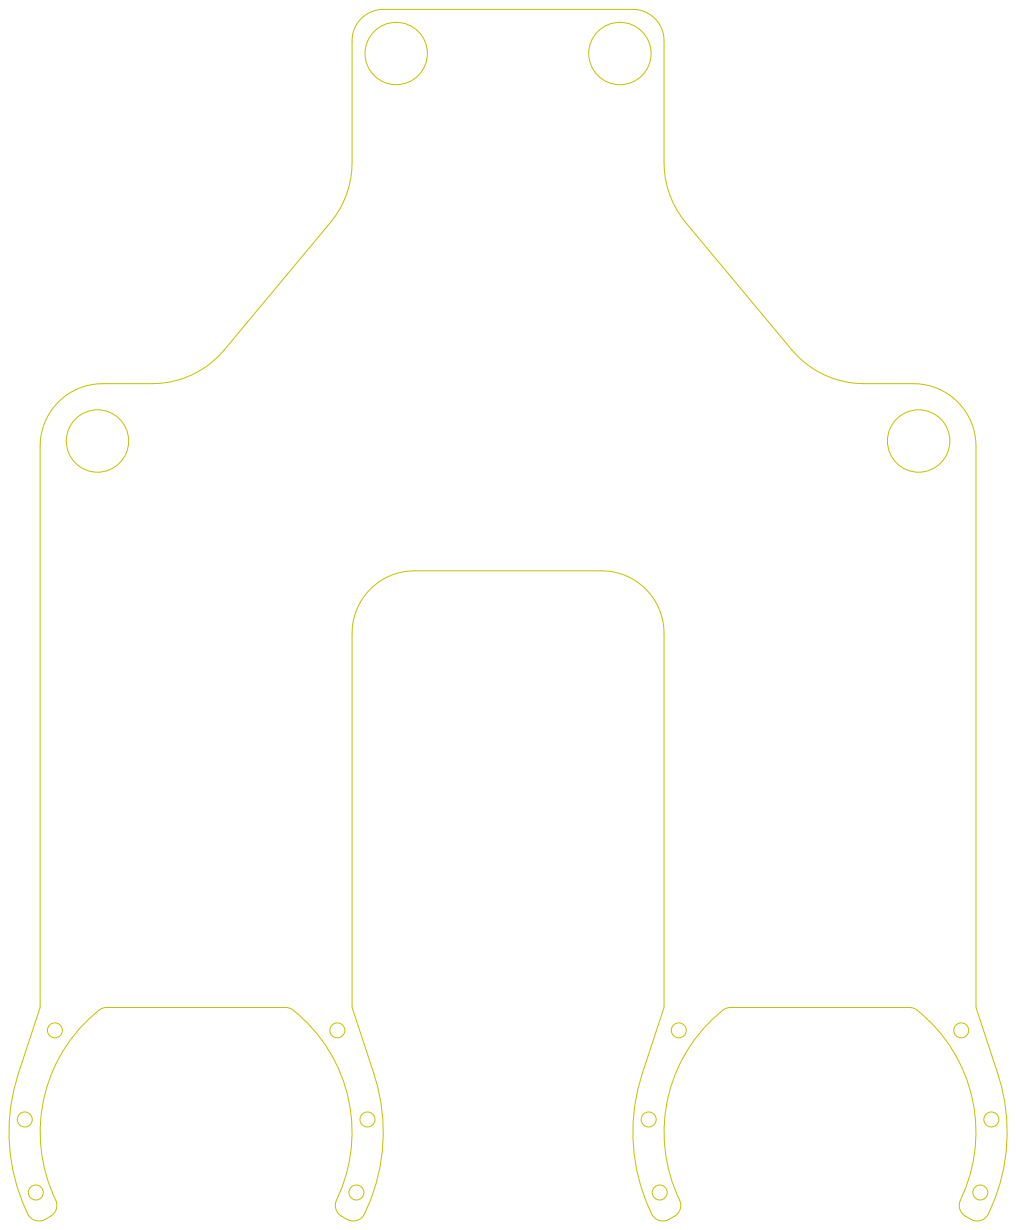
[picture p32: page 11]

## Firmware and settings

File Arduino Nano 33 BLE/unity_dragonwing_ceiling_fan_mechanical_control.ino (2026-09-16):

         /////////////////////////////////////////////  
        //   A study on VLM-driven ceiling fan     //
       //       airflow analysis w/ Unity         //
      //             ---------------             //
     //          (Arduino Nano 33 BLE)          //           
    //             by Kutluhan Aktar           // 
   //                                         //
///////////////////////////////////////////////
//
//
//
// Utilizing VLMs to determine dual fan configurations for optimum cooling based on LiDAR-oriented real-time airflow simulations on Unity.
//
// For more information:
// https://www.kutluhanaktar.com/projects/A_study_on_VLM_driven_ceiling_fan_airflow_analysis_w_Unity
//
//
// Connections
// Arduino Nano 33 BLE :
//                                BTS7960B DC Motor Driver (40A) [First]
// 5V      ------------------------ VCC
// GND     ------------------------ GND
// D2      ------------------------ R_PWM
// D3      ------------------------ L_PWM
// 3.3V    ------------------------ R_EN
// 3.3V    ------------------------ L_EN
//                                BTS7960B DC Motor Driver (40A) [Second]
// 5V      ------------------------ VCC
// GND     ------------------------ GND
// D4      ------------------------ R_PWM
// D5      ------------------------ L_PWM
// 3.3V    ------------------------ R_EN
// 3.3V    ------------------------ L_EN
//                                A4988 Driver Module [First]
// 3.3V    ------------------------ VDD
// GND     ------------------------ GND
// D6      ------------------------ DIR
// D7      ------------------------ STEP
//                                A4988 Driver Module [Second]
// 3.3V    ------------------------ VDD
// GND     ------------------------ GND
// D8      ------------------------ DIR
// D9      ------------------------ STEP
//                                A4988 Driver Module [Third]
// 3.3V    ------------------------ VDD
// GND     ------------------------ GND
// D10     ------------------------ DIR
// D11     ------------------------ STEP
//                                A4988 Driver Module [Fourth]
// 3.3V    ------------------------ VDD
// GND     ------------------------ GND
// D12     ------------------------ DIR
// D13     ------------------------ STEP
//                                Grove - Triple Color E-Ink Display (1.54")
// GND     ------------------------ GND
// 3.3V    ------------------------ VCC
// TX      ------------------------ RX
// RX      ------------------------ TX
//                                2 Channel Relay Module
// GND     ------------------------ GND
// A6      ------------------------ IN1
// A7      ------------------------ IN2
// 5V      ------------------------ VCC
//                                KY-040 Rotary Encoder Module [First]
// GND     ------------------------ GND
// 3.3V    ------------------------ +
// A1      ------------------------ DT
// A0      ------------------------ CLK
//                                KY-040 Rotary Encoder Module [Second]
// GND     ------------------------ GND
// 3.3V    ------------------------ +
// A3      ------------------------ DT
// A2      ------------------------ CLK
//                                Motor Speed Sensor (LM393 Optical) [First]
// GND     ------------------------ GND
// A4      ------------------------ OUT
// 3.3V    ------------------------ VCC
//                                Motor Speed Sensor (LM393 Optical) [Second]
// GND     ------------------------ GND
// A5      ------------------------ OUT
// 3.3V    ------------------------ VCC


// Include the required libraries:
#include <ArduinoBLE.h>

// Import the custom interfaces to show them on the Grove - triple color e-ink display.
#include "interfaces.h"

// Declare the BLE service hosted by this device.
BLEService ceiling_fan("9755c88d-cae7-43c6-9013-16d456e05bf6");

// Declare BLE data characteristics and allow the remote device (central) to write, read, or notify.
BLEByteCharacteristic first_fan_speed("9756c88d-cae7-43c6-9013-16d456e05bf6", BLERead | BLEWrite);
BLEByteCharacteristic first_fan_vertical("9757c88d-cae7-43c6-9013-16d456e05bf6", BLERead | BLEWrite);
BLEByteCharacteristic first_fan_horizontal("9758c88d-cae7-43c6-9013-16d456e05bf6", BLERead | BLEWrite);
BLEByteCharacteristic second_fan_speed("9759c88d-cae7-43c6-9013-16d456e05bf6", BLERead | BLEWrite);
BLEByteCharacteristic second_fan_vertical("9760c88d-cae7-43c6-9013-16d456e05bf6", BLERead | BLEWrite);
BLEByteCharacteristic second_fan_horizontal("9761c88d-cae7-43c6-9013-16d456e05bf6", BLERead | BLEWrite);
BLEByteCharacteristic first_light("9762c88d-cae7-43c6-9013-16d456e05bf6", BLERead | BLEWrite);
BLEByteCharacteristic second_light("9763c88d-cae7-43c6-9013-16d456e05bf6", BLERead | BLEWrite);
BLEShortCharacteristic first_fan_status("9764c88d-cae7-43c6-9013-16d456e05bf6", BLERead | BLENotify);
BLEShortCharacteristic second_fan_status("9765c88d-cae7-43c6-9013-16d456e05bf6", BLERead | BLENotify);
BLEByteCharacteristic homing_status("9766c88d-cae7-43c6-9013-16d456e05bf6", BLERead | BLEWrite);
BLEByteCharacteristic active_procedures("9767c88d-cae7-43c6-9013-16d456e05bf6", BLERead | BLEWrite);

// Define the motor speed sensor (LM393 Optical) pin configurations.
#define first_speed_sensor       A4
#define second_speed_sensor      A5

// Define the 2 channel relay module pin configurations.
#define relay_IN1                A6
#define relay_IN2                A7

// Declare a struct containing RS775 DC motor (12V - 12000 rpm) configurations.
struct fan_motors {
  static constexpr int motor_num = 2;
  int pins[motor_num][2] = {
    {D2, D3}, // R_PWM, L_PWM
    {D4, D5}
  };
  int speed_level[5] = {0, 50, 120, 180, 255};
  int first_motor_speed = 0,
      second_motor_speed = 0;
  float homing_angle_buffer[motor_num] = {0, 0};
  volatile boolean horizontally_homed[motor_num] = {false, false};
};

// Declare a struct containing Nema 17 (17HS3401) stepper motor configurations.
struct gear_motors {
  static constexpr int motor_num = 4;
  int pins[motor_num][2] = {
    {D6, D7}, // DIR, STEP
    {D8, D9},
    {D10, D11},
    {D12, D13}
  };
  int speed = 12000,
      stepsPerRevolution = 200;
  float oneDegreeStepX = 0.2;
  int oneDegreeAccX = 10;
  float oneDegreeStepY = 0.5;
  int oneDegreeAccY = 5;
  
      
};

// Declare a struct containing rotary encoder configurations.
struct encoder {
  static constexpr int encoder_num = 2;
  int pins[encoder_num][2] = {
    {A0, A1}, // CLK, DT
    {A2, A3}
  };
  volatile long ticks[encoder_num] = {0, 0};
  long last_ticks[encoder_num] = {0, 0};
  float angle[encoder_num] = {0, 0};
  const float ticks_per_rev = 20.0,
              gear_ratio = 2;
  volatile boolean buffer_given = false;
};

// Define data holders.
struct fan_motors fan_motors;
struct gear_motors gear_motors;
struct encoder encoder;
String current_first_motor_task = "idle",
       current_second_motor_task = "idle",
       latest_performed_task = "idle";
volatile boolean screen_active = true,
                 screen_change = false,
                 ble_phone_con = false,
                 ble_computer_con = false,
                 unity_active = false;


void setup() {

  Serial.begin(115200);
  delay(1000);

  // Initiate the hardware serial port (Serial1) to communicate with the triple color e-ink display.
  Serial1.begin(230400); 
  delay(1000);
  
  // Register pin configurations.
  pinMode(first_speed_sensor, INPUT_PULLUP); pinMode(second_speed_sensor, INPUT_PULLUP);
  pinMode(relay_IN1, OUTPUT); pinMode(relay_IN2, OUTPUT); digitalWrite(relay_IN1, HIGH); digitalWrite(relay_IN2, HIGH);

  // Initial pin configurations for the BTS7960B DC motor drivers to make RS775 DC motors idle at execution.
  for(int i=0; i<fan_motors.motor_num; i++){
    pinMode(fan_motors.pins[i][0], OUTPUT); analogWrite(fan_motors.pins[i][0], 0);
    pinMode(fan_motors.pins[i][1], OUTPUT); analogWrite(fan_motors.pins[i][1], 0);
  }

  // Initial pin configurations to activate the A4988 driver modules.
   for(int i=0; i<gear_motors.motor_num; i++){
    pinMode(gear_motors.pins[i][0], OUTPUT);
    pinMode(gear_motors.pins[i][1], OUTPUT);
  }

  // Initial pin configurations for the rotary encoders.
  for(int i=0; i<encoder.encoder_num; i++){
    pinMode(encoder.pins[i][0], INPUT_PULLUP);
    pinMode(encoder.pins[i][1], INPUT_PULLUP);
  }  

  // Show the default states on the triple color e-ink display.
  if(screen_active) show_screen_e_ink(ble_phone_con, ble_computer_con, unity_active);

  // Initiate the BLE communication procedure.
  while(!BLE.begin()){
    Serial.println("BLE initialization is failed!");
  }
  Serial.println("\nBLE initialization is successful!\n");
  // Print this peripheral device's address information:
  Serial.print("MAC Address: "); Serial.println(BLE.address());
  Serial.print("Service UUID Address: "); Serial.println(ceiling_fan.uuid()); Serial.println();

  // Set the local name this peripheral advertises, which will be shown to central devices.
  BLE.setLocalName("Dragonwing Ceiling Fan");
  // Set the primary service UUID.
  BLE.setAdvertisedService(ceiling_fan);
  // Add the declared BLE data characteristics to the defined primary service.
  ceiling_fan.addCharacteristic(first_fan_speed);
  ceiling_fan.addCharacteristic(first_fan_vertical);
  ceiling_fan.addCharacteristic(first_fan_horizontal);
  ceiling_fan.addCharacteristic(second_fan_speed);
  ceiling_fan.addCharacteristic(second_fan_vertical);
  ceiling_fan.addCharacteristic(second_fan_horizontal);
  ceiling_fan.addCharacteristic(first_light);
  ceiling_fan.addCharacteristic(second_light);
  ceiling_fan.addCharacteristic(first_fan_status);
  ceiling_fan.addCharacteristic(second_fan_status);
  ceiling_fan.addCharacteristic(homing_status);
  ceiling_fan.addCharacteristic(active_procedures);
  // Register the primary service.
  BLE.addService(ceiling_fan);

  // Assign event handlers for connected and disconnected central devices to/from this peripheral.
  BLE.setEventHandler(BLEConnected, blePeripheralConnectHandler);
  BLE.setEventHandler(BLEDisconnected, blePeripheralDisconnectHandler);

  // Assign event handlers for the BLE data characteristics modified (written) by the connected central device.
  // Then, perform the requested task accordingly.
  first_fan_speed.setEventHandler(BLEWritten, perform_tasks_via_BLE);
  first_fan_vertical.setEventHandler(BLEWritten, perform_tasks_via_BLE);
  first_fan_horizontal.setEventHandler(BLEWritten, perform_tasks_via_BLE);
  second_fan_speed.setEventHandler(BLEWritten, perform_tasks_via_BLE);
  second_fan_vertical.setEventHandler(BLEWritten, perform_tasks_via_BLE);
  second_fan_horizontal.setEventHandler(BLEWritten, perform_tasks_via_BLE);
  first_light.setEventHandler(BLEWritten, perform_tasks_via_BLE);
  second_light.setEventHandler(BLEWritten, perform_tasks_via_BLE);
  homing_status.setEventHandler(BLEWritten, perform_tasks_via_BLE);
  active_procedures.setEventHandler(BLEWritten, perform_tasks_via_BLE);

  // Start advertising with the concluded device settings.
  BLE.advertise();
  Serial.println(("BLE connection is active, waiting for the central device..."));
  delay(5000);

  // Attach seperate interrupt handlers for the rotary encoders.
  attachInterrupt(digitalPinToInterrupt(encoder.pins[0][0]), []() { obtain_encoder_values(encoder.pins[0][0], encoder.pins[0][1], encoder.ticks[0]); }, CHANGE); // Using lambda to pass variables.
  attachInterrupt(digitalPinToInterrupt(encoder.pins[1][0]), []() { obtain_encoder_values(encoder.pins[1][0], encoder.pins[1][1], encoder.ticks[1]); }, CHANGE);

}

void loop() {

  // Estimate the angle (0° - 360°) values of the rotary encoders.
   for(int i=0; i<encoder.encoder_num; i++){
    if(encoder.ticks[i] != encoder.last_ticks[i]){
        encoder.last_ticks[i] = encoder.ticks[i];
        float raw_angle = (encoder.ticks[i] / encoder.ticks_per_rev) * 360.0 / encoder.gear_ratio;
        // Remove the provided horizontal motor buffer angle to zero the encoder position based on the homing speed sensor position.
        encoder.angle[i] = fmod(raw_angle - fan_motors.homing_angle_buffer[i], 360.0);
        if(encoder.angle[i] < 0) encoder.angle[i] += 360.0;
        // After estimating the angle successfully, update the fan status information over BLE.
        int16_t angle = (int16_t)encoder.angle[i];
        if(i == 0){ first_fan_status.writeValue(angle); }
        else if(i == 1){ second_fan_status.writeValue(angle); }
    }   
  }

  // Once the motor buffer angles are set, update the fan status information over BLE immediately, which lets the user see the zeroed encoder angle values without turning encoder knobs.
  if(encoder.buffer_given){
    for(int i=0; i<encoder.encoder_num; i++){
      // Estimate the current angle to precisely zero the encoder position.
      float raw_angle = (encoder.ticks[i] / encoder.ticks_per_rev) * 360.0 / encoder.gear_ratio;
      encoder.angle[i] = fmod(raw_angle - fan_motors.homing_angle_buffer[i], 360.0);
      if(encoder.angle[i] < 0) encoder.angle[i] += 360.0;      
    }
    first_fan_status.writeValue((int16_t)encoder.angle[0]); second_fan_status.writeValue((int16_t)encoder.angle[1]);
    encoder.buffer_given = false;
  }

  // Once the motor speed sensors detect the homing pins, update the fan status information immediately.
  if(digitalRead(first_speed_sensor) && !fan_motors.horizontally_homed[0]){
    first_fan_status.writeValue(-1);
    fan_motors.horizontally_homed[0] = true;
  }else if(!digitalRead(first_speed_sensor) && fan_motors.horizontally_homed[0]){
    first_fan_status.writeValue(-2);
    fan_motors.horizontally_homed[0] = false;
  }
  if(digitalRead(second_speed_sensor) && !fan_motors.horizontally_homed[1]){
    second_fan_status.writeValue(-1);
    fan_motors.horizontally_homed[1] = true;
  }else if(!digitalRead(second_speed_sensor) && fan_motors.horizontally_homed[1]){
    second_fan_status.writeValue(-2);
    fan_motors.horizontally_homed[1] = false;
  }    
 
  // Once the operation states change, update the triple color e-ink display.
  if(screen_change && screen_active){
    show_screen_e_ink(ble_phone_con, ble_computer_con, unity_active);
    screen_change = false;
  }

  // To avoid interruption issues, seperate task from the primary BLE poll loop.
  /* First (Left) ceiling fan motor tasks. */
  if(current_first_motor_task != "idle"){
    if(current_first_motor_task == "one_degree_down" && latest_performed_task != "one_degree_down"){
      driver_bevel_gear_move(0, gear_motors.oneDegreeStepY, gear_motors.oneDegreeAccY, "TD", "D_R");
      latest_performed_task = "one_degree_down";
    }
    if(current_first_motor_task == "one_degree_up" && latest_performed_task != "one_degree_up"){
      driver_bevel_gear_move(0, gear_motors.oneDegreeStepY, gear_motors.oneDegreeAccY, "TD", "U_L");
      latest_performed_task = "one_degree_up";
    }    
    if(current_first_motor_task == "one_degree_right" && latest_performed_task != "one_degree_right"){
      driver_bevel_gear_move(0, gear_motors.oneDegreeStepX, gear_motors.oneDegreeAccX, "OP", "D_R");
      latest_performed_task = "one_degree_right";
    } 
    if(current_first_motor_task == "one_degree_left" && latest_performed_task != "one_degree_left"){
      driver_bevel_gear_move(0, gear_motors.oneDegreeStepX, gear_motors.oneDegreeAccX, "OP", "U_L");
      latest_performed_task = "one_degree_left";
    }
    if(current_first_motor_task == "speed_update"){
      analogWrite(fan_motors.pins[0][0], fan_motors.first_motor_speed);
      analogWrite(fan_motors.pins[0][1], 0);
    }
    current_first_motor_task = "idle";
    delay(200);                 
  }

  /* Second (Right) ceiling fan motor tasks. */
  if(current_second_motor_task != "idle"){
    if(current_second_motor_task == "one_degree_down" && latest_performed_task != "one_degree_down"){
      driver_bevel_gear_move(2, gear_motors.oneDegreeStepY, gear_motors.oneDegreeAccY, "TD", "D_R");
      latest_performed_task = "one_degree_down";
    }
    if(current_second_motor_task == "one_degree_up" && latest_performed_task != "one_degree_up"){
      driver_bevel_gear_move(2, gear_motors.oneDegreeStepY, gear_motors.oneDegreeAccY, "TD", "U_L");
      latest_performed_task = "one_degree_up";
    }    
    if(current_second_motor_task == "one_degree_right" && latest_performed_task != "one_degree_right"){
      driver_bevel_gear_move(2, gear_motors.oneDegreeStepX, gear_motors.oneDegreeAccX, "OP", "D_R");
      latest_performed_task = "one_degree_right";
    } 
    if(current_second_motor_task == "one_degree_left" && latest_performed_task != "one_degree_left"){
      driver_bevel_gear_move(2, gear_motors.oneDegreeStepX, gear_motors.oneDegreeAccX, "OP", "U_L");
      latest_performed_task = "one_degree_left";
    }
    if(current_second_motor_task == "speed_update"){
      analogWrite(fan_motors.pins[1][0], 0);
      analogWrite(fan_motors.pins[1][1], fan_motors.second_motor_speed);
    }
    current_second_motor_task = "idle";
    delay(200);                 
  }  

  // Initiate the built-in loop of the BLE class (poll) to process BLE events.
  BLE.poll();

}

void driver_bevel_gear_move(int gear_set, float step_number, int acc, String _state, String _dir){
  /*
      Move the requested driver bevel gear set by controlling the rotation of the associated stepper motors.
      Gear Set State:
        Tandem [TD]: rotate the target stepper motors at the same direction at the same speed.
        Opposite [OP]: rotate the target stepper motors at opposite directions at the same speed.
      Gear Set Direction:
        Up or Left [U_L]: if the gear state is tandem, mechanism moves left. if the gear state is opposite, the mechanism moves up.
        Down or Right [D_R]: if the gear state is tandem, mechanism moves right. if the gear state is opposite, the mechanism moves down.
      Gear Set Numbers:
        0: First (Left) ceiling fan driver bevel gears.
        2: Second (Right) ceiling fan driver bevel gears.
  */
  if(_state == "TD" && _dir == "U_L"){
    digitalWrite(gear_motors.pins[gear_set][0], LOW);
    digitalWrite(gear_motors.pins[gear_set+1][0], HIGH);
  }
  else if(_state == "TD" && _dir == "D_R"){
    digitalWrite(gear_motors.pins[gear_set][0], HIGH);
    digitalWrite(gear_motors.pins[gear_set+1][0], LOW);
  }  
  if(_state == "OP" && _dir == "U_L"){
    digitalWrite(gear_motors.pins[gear_set][0], HIGH);
    digitalWrite(gear_motors.pins[gear_set+1][0], HIGH);
  }
  else if(_state == "OP" && _dir == "D_R"){
    digitalWrite(gear_motors.pins[gear_set][0], LOW);
    digitalWrite(gear_motors.pins[gear_set+1][0], LOW);
  } 

  // Calculate the total rotation number to achieve the requested step number based on the defined revolution number.
  float rotation_number = gear_motors.stepsPerRevolution * step_number;
  // Then, rotate the target stepper motors accordingly.
  for(int i = 0; i < (int)rotation_number; i++){
    digitalWrite(gear_motors.pins[gear_set][1], HIGH);
    digitalWrite(gear_motors.pins[gear_set+1][1], HIGH);
    delayMicroseconds(gear_motors.speed/acc);
    digitalWrite(gear_motors.pins[gear_set][1], LOW);
    digitalWrite(gear_motors.pins[gear_set+1][1], LOW);
    delayMicroseconds(gear_motors.speed/acc);
  }  

}

void obtain_encoder_values(int clkPin, int dtPin, volatile long &ticks){
  // Update the tick value of the given rotary encoder.
  if(digitalRead(clkPin) != digitalRead(dtPin)){
    ticks++;
  }else{
    ticks--;
  }
}
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
